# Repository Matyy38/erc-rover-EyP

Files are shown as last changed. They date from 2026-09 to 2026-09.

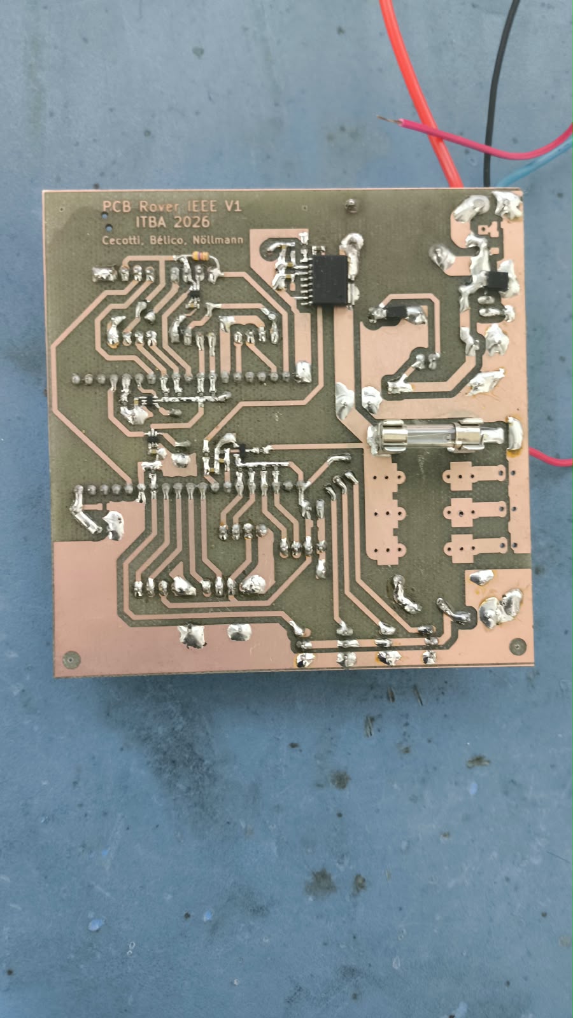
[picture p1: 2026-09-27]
audiovisual-presentacion/Foto pcb2.jpeg

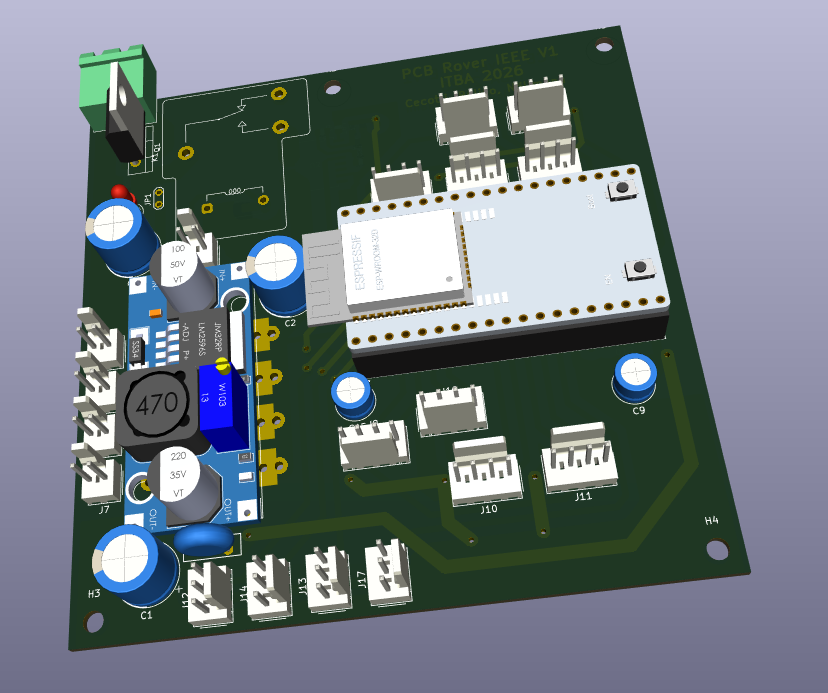
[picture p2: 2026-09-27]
audiovisual-presentacion/PCB Simulación 3D.png

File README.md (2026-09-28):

---
titulo: Rover ERC — subsistema de Electrónica y Potencia
estado: vigente
fecha: 2026-09-28
fuente: migracion.md (árbol y mapeo de los cuatro documentos fuente)
---

# Rover ERC — Electrónica y Potencia

Documentación del subsistema de Electrónica y Potencia del rover del European Rover Challenge
(IEEE ITBA I+D). Dos frentes: el **rover final** (40 kg, bus de 24 V, swerve de 4 ruedas) y el **modelo a
escala**, que es un instrumento de medición para cerrar la especificación de motores sin comprar
motores de tamaño real a ciegas.

**Empezá por [00-contexto/00-contexto-maestro.md](00-contexto/00-contexto-maestro.md).** Tiene el
estado, los conflictos abiertos y el mapa.

---

## Árbol

```
rover-erc/
├── README.md
├── CLAUDE.md
├── 00-contexto/
│   ├── 00-contexto-maestro.md
│   ├── 01-alcance-y-fronteras.md
│   ├── 02-filosofia-de-diseno.md
│   ├── 03-conflictos-abiertos.md
│   ├── 04-decisiones-descartadas.md
│   └── 05-principios-transversales.md
├── 10-rover-final/
│   ├── 10-locomocion/
│   │   ├── requisitos-motor.md
│   │   └── candidatos-motores.md
│   └── 20-potencia/
│       ├── presupuesto-corriente.md
│       └── cableado-y-protecciones.md
├── 20-modelo-escala/
│   ├── 00-estado-actual.md
│   ├── 10-metodologia-similitud.md
│   ├── 20-electronica/
│   │   ├── arquitectura-electrica.md
│   │   ├── encoders-pcnt.md
│   │   ├── drivers-bts7960.md
│   │   ├── direccion-swerve-servos.md
│   │   ├── sensado-corriente.md
│   │   └── protecciones-desacople.md
│   ├── 30-pcb/
│   │   ├── especificacion.md
│   │   ├── decisiones-layout.md
│   │   ├── mapa-conectores.md
│   │   ├── bom.md
│   │   └── pendientes-de-verificacion.md
│   ├── 40-firmware/
│   │   └── mapa-gpio.md
│   └── 50-ensayos/
│       ├── instrumentacion.md
│       └── plan-de-ensayos.md
├── 30-componentes/
├── 40-proveedores-costos/
├── 90-archivo/
│   ├── analisis-sensado-superado.md
│   ├── migracion-2026-09-16.md
│   └── fuentes-originales/
├── audiovisual-presentacion/
└── pcb_V1/
```

---

## Índice

### 00-contexto

| Archivo | Qué tiene |
|---|---|
| [00-contexto-maestro.md](00-contexto/00-contexto-maestro.md) | Documento raíz: estado de los dos frentes, conflictos abiertos, instrumentación, próximos pasos y mapa del repo. |
| [01-alcance-y-fronteras.md](00-contexto/01-alcance-y-fronteras.md) | Qué entra y qué no en el subsistema, con la tabla de interfaces con Mecánica. |
| [02-filosofia-de-diseno.md](00-contexto/02-filosofia-de-diseno.md) | Las reglas no negociables y dónde se aplica cada una. |
| [03-conflictos-abiertos.md](00-contexto/03-conflictos-abiertos.md) | Los tres conflictos que bloquean decisiones y la consulta consolidada a Mecánica. |
| [04-decisiones-descartadas.md](00-contexto/04-decisiones-descartadas.md) | Tabla única de lo que se evaluó y no quedó, con el motivo. |
| [05-principios-transversales.md](00-contexto/05-principios-transversales.md) | Las trece reglas ganadas en el proyecto que aplican más allá de su caso. |

### 10-rover-final

| Archivo | Qué tiene |
|---|---|
| [10-locomocion/requisitos-motor.md](10-rover-final/10-locomocion/requisitos-motor.md) | Torque, velocidad y potencia por rueda; discrepancias de diámetro; implicancias eléctricas. |
| [10-locomocion/candidatos-motores.md](10-rover-final/10-locomocion/candidatos-motores.md) | Estado por candidato, criterio de reducción y criterio de búsqueda del reemplazo. |
| [20-potencia/presupuesto-corriente.md](10-rover-final/20-potencia/presupuesto-corriente.md) | Del torque medido a la corriente de la PDB: escenarios, techo de tracción, potencia continua. |
| [20-potencia/cableado-y-protecciones.md](10-rover-final/20-potencia/cableado-y-protecciones.md) | Calibres, fusibles y la cadena conector-fusible-cable del rover final. |

### 20-modelo-escala

| Archivo | Qué tiene |
|---|---|
| [00-estado-actual.md](20-modelo-escala/00-estado-actual.md) | Estado de validación de la placa por bloque y cambios confirmados respecto del PDF. |
| [10-metodologia-similitud.md](20-modelo-escala/10-metodologia-similitud.md) | λ vigente, revisión de escala por la masa real, altura del CM y constantes recalculadas. |
| [20-electronica/arquitectura-electrica.md](20-modelo-escala/20-electronica/arquitectura-electrica.md) | Cadena de potencia, rieles y presupuesto del riel de 3,3 V. |
| [20-electronica/encoders-pcnt.md](20-modelo-escala/20-electronica/encoders-pcnt.md) | Acondicionamiento de los ocho canales y uso del periférico PCNT. |
| [20-electronica/drivers-bts7960.md](20-modelo-escala/20-electronica/drivers-bts7960.md) | Habilitaciones, estado del canal 4 en el arranque (V1) y desacople local. |
| [20-electronica/direccion-swerve-servos.md](20-modelo-escala/20-electronica/direccion-swerve-servos.md) | Margen del riel de servos (V3), el PTC único y el estado en el arranque. |
| [20-electronica/sensado-corriente.md](20-modelo-escala/20-electronica/sensado-corriente.md) | TMCS1126B4: qué mide, rango, acondicionamiento, umbral de OC (V9) y calibración. |
| [20-electronica/protecciones-desacople.md](20-modelo-escala/20-electronica/protecciones-desacople.md) | Capas de protección, polaridad inversa (V2), TVS (V5, V6), inrush del relé (V7). |
| [30-pcb/especificacion.md](20-modelo-escala/30-pcb/especificacion.md) | Datos generales, corrientes de diseño y anchos de pista. |
| [30-pcb/decisiones-layout.md](20-modelo-escala/30-pcb/decisiones-layout.md) | Masas en estrella, ruteo del TMCS1126, potencia, analógico y mecánica. |
| [30-pcb/mapa-conectores.md](20-modelo-escala/30-pcb/mapa-conectores.md) | Tabla completa de J1 a J19, márgenes de los conectores (V4) y convenciones de cableado. |
| [30-pcb/bom.md](20-modelo-escala/30-pcb/bom.md) | Lista por referencia, ítems sin valor definido y compras fuera de placa. |
| [30-pcb/pendientes-de-verificacion.md](20-modelo-escala/30-pcb/pendientes-de-verificacion.md) | Los doce puntos V1 a V12, cómo se confirma cada uno y dónde se discute. |
| [40-firmware/mapa-gpio.md](20-modelo-escala/40-firmware/mapa-gpio.md) | **Fuente única de verdad del pinout**, con la estrategia de arranque seguro. |
| [50-ensayos/instrumentacion.md](20-modelo-escala/50-ensayos/instrumentacion.md) | Cadena de medición, tiro en barra, instrumento externo y riesgos de medición. |
| [50-ensayos/plan-de-ensayos.md](20-modelo-escala/50-ensayos/plan-de-ensayos.md) | Ensayo de ángulo de deslizamiento, Ensayo A fuera de la PDB y próximos pasos. |

### Carpetas por llenar y archivo

| Archivo | Qué tiene |
|---|---|
| [30-componentes/README.md](30-componentes/README.md) | Ficha por componente y enlaces a hojas de datos. Vacía. |
| [40-proveedores-costos/README.md](40-proveedores-costos/README.md) | Proveedores y costos de importación. Vacía. |
| [90-archivo/README.md](90-archivo/README.md) | Versiones superadas y ramas muertas. **No usar como fuente.** |
| [90-archivo/analisis-sensado-superado.md](90-archivo/analisis-sensado-superado.md) | El análisis que suponía que el TMCS1126 medía el total de la PDB, con su nota de trazabilidad. |
| [90-archivo/migracion-2026-09-16.md](90-archivo/migracion-2026-09-16.md) | Plan con el que se armó este árbol a partir de los cuatro documentos fuente. |
| [90-archivo/fuentes-originales/README.md](90-archivo/fuentes-originales/README.md) | Los cuatro documentos previos a la migración, sin tocar. |

### Material para el equipo

| Archivo | Qué tiene |
|---|---|
| [audiovisual-presentacion/guia-ingreso-EyP-2026-09.docx](audiovisual-presentacion/guia-ingreso-EyP-2026-09.docx) | Guía de ingreso: resumen del repo para ponerse al día. Corte al 28-sep-2026; si no coincide con el repo, manda el repo. |
| [audiovisual-presentacion/presentacion-ingreso-EyP-2026-09.pptx](audiovisual-presentacion/presentacion-ingreso-EyP-2026-09.pptx) | Presentación de ingreso al subsistema. |
| [pcb_V1/](pcb_V1/) | Proyecto de KiCad de la placa del modelo, para descargar. El análisis está en `20-modelo-escala/`. |

---

## Reglas de trabajo sobre el repo

- **El mapa de GPIO es fuente única de verdad.** Si una tabla de pines aparece en otro archivo, ese
  archivo enlaza al mapa, no lo copia.
- **Los puntos V1 a V12 son hipótesis, no defectos.** Al cerrar uno, se actualiza su fila con el
  resultado de la medición.
- **La placa ya está fabricada y soldada.** Toda propuesta de cambio dice si es un corte y un puente,
  un componente a reemplazar, o un rediseño.
- **Los archivos de KiCad están en `pcb_V1/` para descargar.** Lo que salió de analizarlos está
  asentado en markdown: los datos se buscan ahí.
- **Cada dato técnico tiene un solo dueño.** El contexto maestro es un índice de estado: resume y
  enlaza, no copia números. Si hay diferencia, manda el archivo de detalle.
- **`90-archivo/` es historia.** No se usa como fuente.

## Convenciones

- Contenido en español. Nombres de archivo en minúscula, sin tildes ni espacios, con guiones.
- Carpetas numeradas para forzar orden de lectura.
- Frontmatter YAML con `titulo`, `estado`, `fecha` y `fuente` en cada archivo.
- Enlaces markdown relativos, nunca wikilinks.
- Entre 40 y 400 líneas por archivo de contenido. Por debajo de 40, fusionar con el contiguo.
- **Los archivos de KiCad se versionan en `pcb_V1/` solo para descarga.** Lo que sale de
  analizarlos se documenta en markdown.
- Registro de decisiones = tabla de descartados, no ADR formales.
- Dentro de tablas, decimales en texto plano con coma. LaTeX solo fuera de tablas.

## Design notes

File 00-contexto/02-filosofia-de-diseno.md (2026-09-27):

---
titulo: Filosofía de diseño — reglas no negociables
estado: vigente
fecha: 2026-09-16
fuente: 00-contexto-maestro.md §3
---

# Filosofía de diseño

Las reglas que no se discuten en cada decisión porque ya se discutieron una vez. Versión corta en el
[contexto maestro](00-contexto-maestro.md) §2.

---

## 1. Reglas

- **COTS primero.** PCB custom solo si lo justifica espacio, peso o ruteo de EMI.
- **Sobredimensionar por seguridad, optimizar por peso y espacio.**
- **Star grounding estricto.** El retorno de motores no comparte cobre con el de lógica ni con el
  analógico en ningún tramo.
- **Cable de silicona en potencia.** Norma AWG.
- **Prohibido protoboard y cables Dupont.** Fretting bajo vibración, contactos intermitentes
  imposibles de diagnosticar. Siempre conectores con traba: XT60, Molex, Anderson, bornera.
- **E-Stop y fusibles innegociables.** El fusible protege el cableado, no la carga.
- **Punteras tubulares** en todo cable multifilar que entre a bornera.

Escenarios contra los que se juzga todo diseño: vibración continua, corriente de bloqueo, estrés
térmico.

---

## 2. Dónde se aplica cada regla

Ninguna de estas reglas es abstracta: todas tienen su caso concreto en la placa del modelo o en el
cableado del rover final. La tabla es el índice de esos casos.

| Regla | Caso concreto | Dónde se discute |
|---|---|---|
| COTS primero | Módulos BTS7960, LM2596 y ESP32-DEVKITC comprados hechos; la PCB propia es solo la distribución | [bom.md](../20-modelo-escala/30-pcb/bom.md) |
| Sobredimensionar por seguridad | Anchos de pista IPC-2221 con ΔT de 10 °C, planos en ambas caras reforzados con estaño | [especificacion.md](../20-modelo-escala/30-pcb/especificacion.md) |
| Star grounding estricto | Dos vertidos de masa unidos en un solo punto; el retorno del sensor va a masa lógica | [decisiones-layout.md](../20-modelo-escala/30-pcb/decisiones-layout.md) |
| Cable de silicona, norma AWG | Tabla de calibres por tramo, de 12–14 AWG en batería a 22–24 AWG en señal | [mapa-conectores.md](../20-modelo-escala/30-pcb/mapa-conectores.md) |
| Prohibido protoboard y Dupont | Conectores Molex KK-254 con traba en toda la placa; XT en el instrumento externo | [mapa-conectores.md](../20-modelo-escala/30-pcb/mapa-conectores.md) |
| E-Stop y fusibles | Seta NC sobre la bobina del relé, fusible por driver, PTC en el riel de servos | [protecciones-desacople.md](../20-modelo-escala/20-electronica/protecciones-desacople.md) |
| El fusible protege el cableado | La cadena conector-fusible-cable del rover final se dimensiona junta | [cableado-y-protecciones.md](../10-rover-final/20-potencia/cableado-y-protecciones.md) |
| Punteras tubulares | Obligatorias en todo multifilar que entre a bornera a tornillo | [decisiones-layout.md](../20-modelo-escala/30-pcb/decisiones-layout.md) |

---

## 3. Los tres escenarios de juicio

- **Vibración continua.** Es la que descarta el protoboard y el Dupont, la que obliga a sujetar los
  mazos pesados al chasis cerca de la placa, y la que hace que todo conector tenga traba.
- **Corriente de bloqueo.** Es el peor caso eléctrico: 22 A con las cuatro ruedas trabadas en el
  modelo. Define fusibles, conectores, anchos de pista y el límite del driver. No es condición de
  operación, es condición de falla, pero el hardware la tiene que sobrevivir.
- **Estrés térmico.** Es el que aparece tarde y sin aviso: la disipación de Q1 (V2), la temperatura
  del AMS1117 con el LM2596 en 7,2 V (V10), el margen térmico del motor en continuo.

Las reglas ganadas de estos escenarios que trascienden su caso original están en
[05-principios-transversales.md](05-principios-transversales.md).

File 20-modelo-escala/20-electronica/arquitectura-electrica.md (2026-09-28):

---
titulo: Arquitectura eléctrica de la PCB del modelo
estado: vigente
fecha: 2026-09-27
fuente: pcb-modelo-escala.md, sección arquitectura-electrica
---

# Arquitectura eléctrica

Cadena de potencia, rieles y presupuesto del 3,3 V de la placa del modelo a escala. El mapeo de pines
del ESP32 y la estrategia de arranque seguro **no están acá**: viven en
[40-firmware/mapa-gpio.md](../40-firmware/mapa-gpio.md), que es la fuente única de verdad del pinout.

### Cadena de potencia

```
                         NODO A (12 V protegido, permanente)
 J1          Q1                 |
[Bat +]--->[D  S]-------+-------+--- D1 (TVS SM6T15A) --- GND
 12V/7Ah    IRF9540N    |       |
                        |       +--- D5+R16 (LED de presencia)
                   R14 10k      |
                   D4 16V       +--- JP1 ---+--- C7 1000u
                    (gate)      |           |
                                |           +--- U2 LM2596  --> RIEL "+5V" (a setear en 7,2 V)
                                |           |                     |
                                |           +--- J2 (SETA NC)     +--- ESP1.19 (VIN del devkit)
                                |                  |              +--- C9 100u + C10 1u
                                |                  v              +--- F2 (PTC) --> C1 1000u --> J12/J13/J14/J17 (4 servos)
                                |            K1 bobina A2
                                |            D3 en antiparalelo
                                |            K1 bobina A1 --> GND
                                |
                                +--- K1 contacto 11 (comun)
                                          |
                                     (NO) 14
                                          |
                                     U3 IN- [TMCS1126B4] IN+
                                                          |
                                                    RIEL +12V CONMUTADO
                                                          |
                                          +------+--------+--------+------+
                                          F5     F3       F4       F6     C2 1000u + R6 (divisor)
                                          |      |        |        |
                                         J6     J4       J5       J7
                                      driver1 driver2  driver3  driver4
```

> **Cambios del 27-sep-2026 sobre este diagrama:**
> - **Q1 está puenteado.** El nodo A queda unido directo a la batería; la polaridad se protege con un
>   conector que solo entra en un sentido. Ver [protecciones-desacople.md](protecciones-desacople.md).
> - **ACS712 en la pata de motor de una rueda delantera**, entre driver y motor, fuera de la placa.
>   Se alimenta con un regulador lineal de 5 V propio desde el riel "+5V" y se lee con un ADS1115 en
>   el bus I2C. Ver [sensado-corriente.md](sensado-corriente.md).
> - La batería de plomo alimenta el bus de tracción **sin regular** (10,5 a 14,4 V). Los ensayos lo
>   compensan con lazo cerrado de velocidad y registro de tensión y ciclo de trabajo, no con un
>   convertidor. Ver [50-ensayos/plan-de-ensayos.md](../50-ensayos/plan-de-ensayos.md).

### Rieles

| Riel | Origen | Tensión real | Cargas | Protección propia |
|---|---|---|---|---|
| Batería | J1 | 10,5 - 14,4 V (plomo-ácido 12 V / 7 Ah) | todo | Fusible aéreo (off-board) |
| Nodo A | salida de Q1 (**Q1 puenteado**: nodo A = batería) | Vbat | LM2596, bobina del relé, LED | D1 (TVS); polaridad por conector de un solo sentido |
| +12V conmutado | contacto NO de K1, vía U3 | Vbat - caída del relé - 0,7 mΩ del sensor | 4 drivers, C2, divisor de batería | F3..F6 (uno por driver) |
| "+5V" (nombre de red) | U2 LM2596 | **a setear en 7,2 V**, no 5 V | ESP32 VIN + 4 servos | ninguna en la entrada del ESP32 |
| Riel de servos | +5V detrás de F2 | 7,2 V menos la caída del PTC | 4 servos | F2 (PTC rearmable) |
| +3,3 V | AMS1117 del devkit ESP32 | 3,3 V | ESP32, TMCS, MPU, encoders, pull-ups, enables de los BTS, 3 NLAS | ninguna |

Dos consecuencias arquitectónicas que conviene tener presentes:

1. **La seta corta solamente la tracción.** El LM2596 y la bobina cuelgan del nodo A, aguas arriba
   del relé. Al apretar la seta se desenergiza la bobina, se abren los contactos y muere el bus de
   los drivers, pero **los servos de dirección y el ESP32 siguen alimentados**. Para el modelo a
   escala eso es deseable (la telemetría sobrevive al corte). Si en algún ensayo se necesita que los
   servos también caigan, hay que pasar el LM2596 aguas abajo del relé, y ahí se pierde la
   telemetría post-corte.
2. **V_bat se mide después del relé.** El divisor R6/R5 cuelga del riel +12 V conmutado. Con la seta
   apretada el ESP32 lee 0 V, y el corte por software a 10,5 V se dispararía como falso positivo.
   Se contempla en firmware (enmascarar el corte por baja tensión si la tensión cae de golpe a cero
   con corriente nula) o se mueve el divisor al nodo A.

### Presupuesto del riel de 3,3 V

Todo el 3,3 V de la placa sale del AMS1117 que trae el módulo ESP32. No hay regulador de 3,3 V
propio en la PDB.

| Carga | Consumo estimado |
|---|---|
| ESP32 con Wi-Fi activo | 80 - 120 mA promedio, picos de 300 mA |
| U3 TMCS1126 (Iq) | 11 - 14,5 mA |
| MPU6050 | ~4 mA |
| ADS1115 (27-sep) | <1 mA |
| 4 encoders Hall | 40 - 80 mA (**medir**, es la incógnita grande) |
| 8 pull-ups de 4,7 k, peor caso todos en bajo | 5,6 mA |
| VCC lógico de los 4 BTS7960 + enables | 10 - 30 mA (**medir**) |
| 3 NLAS4157 | despreciable |
| **Total estimado** | **150 - 250 mA, picos de 400 mA** |

Con el LM2596 en 5 V: el AMS1117 disipa (5 - 3,3) x 0,25 = 0,43 W. Se banca.

Con el LM2596 en 7,2 V (la idea anotada en el esquemático para los servos): disipa
(7,2 - 3,3) x 0,25 = 0,98 W. En SOT-223 sobre el cobre mínimo de un devkit, con resistencia térmica
del orden de 60 a 110 °C/W, son 60 a 110 °C de salto sobre ambiente. Vale la pena medir la
temperatura del regulador antes de dejar el sistema andando mucho rato a 7,2 V (V10).

Si el número da alto, tres salidas:
- (a) Dos convertidores: uno a 5 V para el ESP32 y otro a 7,2 V solo para los servos.
- (b) Un regulador de 3,3 V propio en la PDB desde el nodo A, alimentando el ESP32 por 3V3 directo.
  Ojo con no alimentar simultáneamente 5V y 3V3.
- (c) Dejar el LM2596 en 5 V y aceptar menos torque en los servos.

### Mapeo de pines del ESP32 y arranque seguro

Movidos a [40-firmware/mapa-gpio.md](../40-firmware/mapa-gpio.md). Ahí están la tabla completa de
GPIO extraída del `.sch`, la advertencia de numeración de pines del símbolo de KiCad, y la estrategia
de arranque seguro con los conmutadores NLAS4157. **No copiar esa tabla acá ni en ningún otro
archivo:** duplicar el pinout es la forma más probable de romper algo.

De ahí salen dos datos que se usan en este archivo: no queda ningún GPIO libre, y los puntos V1 y
V10 tocan directamente esta arquitectura.

### Notas de arquitectura

- El número de driver (1..4) **no está asociado a una rueda** en ningún lado del esquemático. Los
  encoders sí (FR, FL, RL, RR) y los servos están numerados 1..4. Conviene fijar la correspondencia
  driver N <-> rueda <-> servo N y rotularla en el mazo y en el firmware.
- No hay watchdog externo ni forma de resetear la etapa de potencia sin la seta.
- No hay CAN en esta etapa (decisión explícita del PDF, sigue vigente).

---

## Relacionado

- Protecciones del nodo A, TVS, relé y polaridad inversa: [protecciones-desacople.md](protecciones-desacople.md)
- Sensor de corriente en la rama conmutada: [sensado-corriente.md](sensado-corriente.md)
- Riel de servos y margen del LM2596 (V3): [direccion-swerve-servos.md](direccion-swerve-servos.md)
- Puntos V10 (temperatura del AMS1117) y V12 (lectura de V_bat con la seta apretada): [30-pcb/pendientes-de-verificacion.md](../30-pcb/pendientes-de-verificacion.md)

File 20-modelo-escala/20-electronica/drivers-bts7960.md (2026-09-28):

---
titulo: Drivers BTS7960 del modelo a escala
estado: vigente
fecha: 2026-09-27
fuente: pcb-modelo-escala.md, sección drivers-bts7960
---

# Drivers BTS7960

Validado: se probó un puente H de cada unidad y funcionaron.

### Interfaz

Cada driver usa **dos conectores separados**: uno de señal (4 vías) y uno de potencia (2 vías).

- **Señal:** J10 (BTS7960_1), J11 (BTS7960_2), J15 (BTS7960_3) y J19 (BTS7960_4), Molex KK-254 de 4
  vías. Llevan L_PWM, R_PWM, +3,3 V y GND. En J19, **R_PWM_4 no viene directo del ESP32 sino de U1**.
- **Potencia:** J6 (driver 1), J4 (driver 2), J5 (driver 3) y J7 (driver 4), Molex KK-254 de 2 vías,
  cada uno detrás de su fusible.

Pinout completo con huella y corriente nominal en
[30-pcb/mapa-conectores.md](../30-pcb/mapa-conectores.md). GPIO de origen de cada línea PWM en
[40-firmware/mapa-gpio.md](../40-firmware/mapa-gpio.md).

La correspondencia fusible-driver **no es correlativa** (F3 va al driver 2, F5 al driver 1).
Conviene dejarlo serigrafiado.

### Habilitaciones

Los `R_EN` y `L_EN` de los cuatro módulos se alimentan desde el pin 3 de cada conector de señal, que
va a +3,3 V permanente. Es decir: **los puentes H están habilitados desde que hay 3,3 V, y el estado
de reposo se delega enteramente a las líneas PWM**. Esto ahorra 4 GPIO, con dos consecuencias:

1. No hay forma de apagar los puentes por hardware sin cortar el bus de 12 V con el relé.
2. Queda libre el único mecanismo de apagado rápido disponible. Ver la propuesta en
   [sensado-corriente.md](sensado-corriente.md) para engancharle el pin OC del TMCS1126.

### Estado del canal 4 durante el arranque (V1)

De la tabla de verdad del NLAS4157 se desprende que, durante la ventana de arranque del ESP32,
`R_PWM_4` quedaría en 3,3 V:

- IO5 arranca en ALTO (pull-up interno, latcheado por el strapping).
- U1 tiene B1 a +3,3 V y B0 a GND, así que su salida A copia a S.
- L_PWM_4 (IO23) es un GPIO común: al reset queda como entrada sin pull. El BTS7960 tiene pull-down
  interno en IN, lo cual cubre a L_PWM_4 pero no a R_PWM_4.
- Los enables están activos de forma permanente.

Si el análisis es correcto, el driver 4 recibiría R_PWM alto y L_PWM bajo, y el motor giraría hasta
que el firmware tome el control. **Esto hay que confirmarlo o descartarlo con osciloscopio**, porque
hay al menos dos cosas que podrían hacer que no pase: el mapeo de números de pin del símbolo
reutilizado (U1 usa el símbolo `RF_Switch:MASWSS0136` renombrado a NLAS4157; si la numeración del
símbolo o de la huella no coincidiera con el NLAS4157 real, la conclusión cambia), y el
comportamiento real de la entrada del módulo BTS7960 a 3,3 V de VCC.

Medición concreta: disparar el osciloscopio en el flanco de EN del ESP32 y mirar R_PWM_4 y L_PWM_4
durante todo el arranque, con el conector de potencia del driver 4 desconectado.

> **Mitigación aplicada (27-sep-2026).** Se soldó una **resistencia de pull-up en L_PWM_4** (valor
> a asentar). Durante el arranque las dos entradas del driver 4 quedan en alto: las dos llaves
> superiores encendidas, los dos bornes del motor al mismo potencial, motor frenado y sin corriente.
> Es un agregado de componente, sin cortes. **V1 sigue abierto hasta verificarlo:** osciloscopio en
> R_PWM_4 y L_PWM_4 durante el arranque, confirmando que L_PWM_4 supera el umbral alto frente al
> pull-down interno del driver, y después, con el motor conectado, que no se mueve al encender.
> Una consecuencia a tener en cuenta en firmware: si el ESP32 se cuelga con IO23 en alta impedancia,
> L_PWM_4 queda en alto.

La alternativa que se había propuesto era **invertir B0/B1 en U1** (B1 a GND, B0 a +3,3 V) e
invertir esa salida PWM por hardware en la matriz de GPIO del LEDC, que no cuesta nada. Si la placa
ya está fabricada son dos cortes y dos puentes. Conviene aplicar el mismo criterio a U4 y U5 aunque
ahí no sea crítico, para que los tres canales queden con la misma convención.

### Otros puntos de los drivers

- **VCC lógico a 3,3 V.** Los módulos BTS7960 comerciales están especificados con VCC de 5 V. Con
  3,3 V andan (el IN es un Schmitt trigger compatible TTL/CMOS) y ya se comprobó en banco, pero se
  está fuera de la especificación nominal del módulo. Conviene verificar la conmutación en todo el
  rango de ciclo de trabajo, no solo en un punto.
- **Los pines IS quedan sin usar.** Consecuencia: no hay medición de corriente por rueda desde la
  placa, solo la total (más la rueda del ACS712, ver
  [sensado-corriente.md](sensado-corriente.md)). **En revisión desde el 27-sep:** con el ADS1115
  sobra un canal. Propuesta: no usarlo como canal de medición en esta campaña (la relación de IS
  tiene mucha dispersión, a menos de ~1 A la domina el error de cero, y con PWM también necesita la
  corrección por D), y a lo sumo cablear un canal experimental en la rueda del ACS712 para medir su
  relación real. Si en falla IS entrega varios mA, sobre 1 k supera los 3,3 V del ADS: resistencia de
  carga ≤ 680 Ω y 10 k en serie. Valores a confirmar en la hoja de datos. Si la relación resulta
  estable, un segundo ADS1115 (0x49) daría las cuatro ruedas.
- **No hay pull-down en las 8 líneas PWM.** Dependen del pull-down interno del BTS7960 durante el
  boot. Mejora barata: un pull-down de 10 k **del lado del driver** (soldado en el módulo o en el
  conector). Del lado del GPIO no protege contra un cable desconectado.
- **Terminación serie.** Con 60 a 100 cm de cable y flancos rápidos, 220 Ω en serie en el origen de
  cada línea PWM ayuda. No están en la placa; se pueden agregar en el conector.
- **Desacople local.** El PDB tiene C2 de 1000 uF, pero los drivers están a 60-100 cm. La
  inductancia de ese cable (del orden de 1 uH/m) domina a frecuencias de conmutación. **Cada
  BTS7960 necesita su propio desacople físicamente en el módulo**: 2 x 470 uF / 25 V / 105 °C de
  bajo ESR más 100 nF cerámico en los bornes. Es hardware fuera de la PCB pero es parte del diseño.

---

El punto V1 y su medición están resumidos en [30-pcb/pendientes-de-verificacion.md](../30-pcb/pendientes-de-verificacion.md).

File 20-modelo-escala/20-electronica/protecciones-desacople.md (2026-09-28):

---
titulo: Protecciones y desacople de la PCB del modelo
estado: vigente
fecha: 2026-09-27
fuente: pcb-modelo-escala.md, sección protecciones-desacople
---

# Protecciones y desacople

> **Cambio (27-sep-2026): Q1 quedó puenteado y no se usa.** La protección contra polaridad inversa
> pasa a ser un conector que solo entra en un sentido: es la alternativa que el propio PDF mencionaba
> (ver más abajo). V2 deja de aplicar. Lo que se pierde es la protección contra el error de conectar
> con cables sueltos o pinzas: **nunca alimentar la placa si no es por ese conector**. La protección
> contra cortocircuito sigue siendo el fusible general. El análisis de Q1 queda abajo como registro.

### Capas de protección

| Capa | Componente | Qué protege |
|---|---|---|
| Fusible general | aéreo, off-board | cableado de batería |
| Polaridad inversa | ~~Q1 IRF9540N + R14 10 k + D4 zener 16 V~~ **Q1 puenteado.** Conector de un solo sentido | toda la placa |
| Sobretensión | D1 SM6T15A en el nodo A | toda la placa |
| Corte de emergencia | J2 (seta NC) -> bobina K1 -> contacto NO | rama de tracción |
| Antirretorno de bobina | D3 en antiparalelo con la bobina | contactos de la seta |
| Sobrecorriente por rama | F3..F6, uno por driver | cableado a cada driver |
| Sobrecorriente en servos | F2 (PTC) | rama de servos |
| Sobrecorriente electrónica | pin OC del TMCS1126 | hoy sin usar (ver V9) |
| Protección de ADC | D2 BAT54S en V_bat | entrada IO32 |
| Indicación | D5 + R16 2,2 k (~4,5 mA) | — |

### Circuito de polaridad inversa

El circuito de compuerta está bien resuelto: el drenador va a la batería y la fuente a la carga, de
manera que el diodo intrínseco conduce en el sentido normal de operación y bloquea con la batería
invertida. La compuerta se lleva a masa por R14 (10 k) y el zener D4 de 16 V limita V_GS, que en el
IRF9540N tiene un máximo de ±20 V. Correcto.

**Disipación en Q1 (V2).** El IRF9540N es canal P, -100 V, -23 A, con **R_DS(on) = 117 mΩ** típico a
VGS = -10 V, en TO-220 vertical. La aritmética de disipación:

| Corriente de bus | Disipación en Q1 | Salto térmico sin disipador (~62 °C/W) |
|---|---|---|
| 1 A | 0,12 W | 7 °C |
| 3 A | 1,05 W | 65 °C |
| 5 A | 2,9 W | 181 °C |
| 10 A | 11,7 W | fuera de rango |
| 22 A (bloqueo) | 56,6 W | fuera de rango |

En banco con poca carga no se nota; el problema aparecería con las cuatro ruedas cargadas. **La
medición que lo define es tocar/medir la temperatura de Q1 con el rover andando sobre terreno**, y
medir la caída de tensión entre drenador y fuente con corriente conocida (a 5 A deberían ser unos
0,6 V si el R_DS(on) es el del datasheet).

Si el número da alto, reemplazos que mantienen el mismo circuito de compuerta:

| Candidato | V_DS | I_D | R_DS(on) | Encapsulado | Disipación a 22 A |
|---|---|---|---|---|---|
| **IRF4905** | -55 V | -74 A | 20 mΩ | TO-220 | 9,7 W (con disipador) |
| AOD4185 / AOB4185 | -40 V | -40 A | ~10 mΩ | TO-252 / TO-263 | 4,8 W |

Alternativa que el propio PDF menciona: eliminar el circuito de polaridad inversa y confiar en un
conector polarizado (XT60). Pierde protección contra el error humano de conectar con caimanes, pero
elimina una fuente de calor y de caída.

### TVS: tensión de trabajo y ubicación (V5, V6)

**V5.** D1 es un **SM6T15A**: 600 W, tensión de trabajo (standoff) de aproximadamente 12,8 V,
ruptura mínima de 14,3 V. Una batería de plomo-ácido flota entre 13,5 y 13,8 V y en carga cíclica
llega a 14,4 V. Con el cargador conectado y el rover energizado, el TVS podría quedar cerca de su
ruptura y conducir. Medición: con la batería recién cargada, medir la corriente de fuga por D1 (o
simplemente su temperatura) con el rover encendido.

Si conduce, reemplazo: **SM6T18A** (standoff 15,3 V) o **SMBJ16A / SMCJ16A** (standoff 16 V). La
tensión de recorte resultante, del orden de 26 V, es segura: los BTS7960 admiten hasta 45 V.

**V6.** El TVS está en el nodo A, aguas arriba del relé. Cuando la seta abre los contactos con los
motores girando, la energía inductiva queda del lado de los drivers, donde no hay TVS: solo C2
(1000 uF), que absorbe la mayor parte, y los diodos intrínsecos de los puentes. Conviene ver con
osciloscopio qué pico aparece en el riel conmutado al abrir la seta a plena marcha. Si es alto, un
segundo TVS (SMBJ16A alcanza) entre el riel conmutado y GND, cerca de C2.

La ubicación del TVS que sí está es correcta en un aspecto: queda **después** del MOSFET de
polaridad inversa, que es donde tiene que ir.

### Inrush del contacto del relé (V7)

K1 es un relé automotriz de 12 V / 40 A. Al cerrar conecta el nodo A contra C2 (1000 uF) más el
desacople local de los drivers (4 x 940 uF si se monta lo recomendado), del orden de **4,8 mF**. La
energía que va al arco de cierre es del orden de `½CV² = 350 mJ` por encendido.

Un contacto de 40 A lo tolera, pero repetido erosiona y puede terminar soldando los contactos. El
síntoma es que la seta deja de cortar y nadie se entera hasta que hace falta. **Verificación
periódica: con la seta apretada, medir continuidad entre el nodo A y el riel conmutado.** Debe ser
circuito abierto.

Mitigación estándar si aparece: **resistencia de precarga de 22 Ω / 5 W en paralelo con el
contacto**. La constante de carga pasa a `22 × 4,8 mF = 106 ms`, o sea que los capacitores ya están
cargados cuando el contacto cierra. No requiere lógica. Para el arco de apertura, un snubber RC
(100 Ω + 100 nF en serie, en paralelo con el contacto).

### Desacople actual

| Riel / punto | Capacitores | Comentario |
|---|---|---|
| Nodo A (entrada del LM2596) | C7 1000 uF | correcto |
| +12 V conmutado | C2 1000 uF | correcto en la placa; el desacople remoto de los drivers es aparte |
| Salida del LM2596 ("+5V") | C9 100 uF + C10 1 uF | correcto |
| Riel de servos (detrás de F2) | C1 1000 uF | correcto en topología |
| +3,3 V | C15 100 uF + C11 1 uF | conviene sumar un 100 nF cerámico pegado al pin 3V3 |
| VS del TMCS1126 | C4 100 n + FB1 + C3 100 n | filtro en pi, muy bien |
| VOC del TMCS1126 | C5 1 uF | el fabricante sugiere 10 uF |
| VCC de cada NLAS4157 | C12, C13, C14 (100 n) | uno por chip, correcto |
| V_bat (ADC) | C6 100 n | con la impedancia de Thevenin del divisor (1,8 k) da un polo en 883 Hz |
| Vout_CS (ADC) | C8 100 n | con R15 de 1 k da un polo en 1,59 kHz |

El único agregado que falta es un 100 nF en 3V3: los electrolíticos de 100 uF tienen ESR e
inductancia que los vuelve poco efectivos por encima de unos cientos de kHz, que es el rango donde
el ESP32 mete escalones de corriente al transmitir por Wi-Fi.

---

Los puntos V2, V5, V6 y V7 y sus mediciones están resumidos en [30-pcb/pendientes-de-verificacion.md](../30-pcb/pendientes-de-verificacion.md).

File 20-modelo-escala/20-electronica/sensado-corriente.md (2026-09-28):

---
titulo: Sensado de corriente — TMCS1126B4 y ACS712 de respaldo
estado: vigente
fecha: 2026-09-27
fuente: pcb-modelo-escala.md, sección sensado-corriente; decisiones del 27-sep-2026 (ADS1115 y ACS712)
---

# Sensado de corriente

### Qué se eligió y por qué

El ACS712-30A del PDF quedó cancelado **como sensor de placa**. En su lugar hay **un TMCS1126B4**
(Texas Instruments), sensor Hall con aislación reforzada, en encapsulado SOIC-10 ancho.

> **27-sep-2026:** el ACS712-30A vuelve, con otro rol: segundo sensor a bordo, en la pata de motor de
> una rueda, leído por el ADS1115. Ver [ACS712 de respaldo](#acs712-de-respaldo-27-sep-2026) al final
> de este archivo.

| Parámetro | Valor |
|---|---|
| Sensibilidad | **100 mV/A** |
| Tensión de salida a corriente cero (VREF interno) | **1,65 V** (variante B, bidireccional) |
| Rango lineal con VS = 3,3 V | **±15,5 A** |
| Resistencia del conductor interno | 0,7 mΩ (a 10 A disipa 70 mW) |
| Ancho de banda | 500 kHz |
| Consumo | 11 a 14,5 mA |
| Tiempo de encendido hasta salida válida | 34 ms |
| Aislación | reforzada, 8 mm de línea de fuga y de aire |

La ventaja frente a un shunt es doble: no hay modo común (la salida ya está referida a masa lógica)
y el aislamiento galvánico lo hace inmune a los flancos del bus conmutado, que es exactamente el
problema que tiene un shunt en el lado alto con un puente H al lado.

### Dónde está conectado

`contacto NO del relé (K1.14) -> U3.IN- -> [conductor interno] -> U3.IN+ -> riel +12 V -> F3..F6 -> drivers`

Tres consecuencias:

1. **Mide únicamente la rama de tracción.** El LM2596 (y con él el ESP32 y los servos) cuelga del
   nodo A, aguas arriba del relé y del sensor. Lo que se lee es la suma de los cuatro motores más el
   consumo lógico de los cuatro drivers. Para el modelo a escala eso es incluso mejor que medir el
   total: el número que sale es directamente la corriente de tracción.
2. **El signo queda invertido.** La corriente entra por IN- y sale por IN+. La función de
   transferencia es `VOUT = IIN·S + VREF` con IIN positiva de IN+ a IN-. Con este cableado,
   descargar la batería hace **bajar** la salida desde 1,65 V:
   `I_traccion = (1,65 - Vout) / 0,1`
   Conviene confirmarlo con una carga conocida en el primer ensayo. Dar vuelta IN+/IN- no gana
   rango, porque el dispositivo es simétrico alrededor de 1,65 V.
3. **No hay medición por rama en la placa.** Con los pines IS de los BTS7960 sin usar, no se puede
   estimar el torque rueda por rueda desde el rover (desde el 27-sep hay una rueda medida con el
   ACS712, ver al final). Para el ensayo de caracterización `τ = K·(I - I0)` no
   molesta (ese ensayo va en banco con un motor por vez), pero sí impide validar el reparto de carga
   entre ruedas durante una trepada.

> **Nota de trazabilidad (16-sep-2026).** Hubo una contradicción entre documentos:
> `metodologia-modelo-escala` §3 afirmaba que el sensor medía el **consumo total de la PDB** y que
> por eso el Ensayo D quedaba invalidado por la contaminación de los servos. **Se resolvió a favor de
> este documento:** el TMCS1126 está en la rama conmutada, aguas abajo del relé, y los servos y el
> ESP32 cuelgan del nodo A, aguas arriba. Lo confirma la consecuencia arquitectónica ya documentada:
> al apretar la seta muere el bus de los drivers pero los servos y el ESP32 siguen alimentados; si
> los servos estuvieran en la rama medida, caerían con la seta. El análisis superado quedó archivado
> en [90-archivo/analisis-sensado-superado.md](../../90-archivo/analisis-sensado-superado.md).
>
> **Consecuencia práctica:** el Ensayo D es válido con el sensor de a bordo. El instrumento externo
> pasó de corrección obligatoria a mejora opcional, y el puente sobre la placa (cortar pista y
> reinsertar el sensor) es innecesario: ya está donde corresponde. Ver
> [50-ensayos/instrumentacion.md](../50-ensayos/instrumentacion.md).

Estado de cada afirmación del análisis superado:

| Afirmación de `metodologia` §3 | Estado |
|---|---|
| El sensor mide el total de la PDB | **Incorrecta.** Mide solo tracción |
| El Ensayo D queda invalidado | **No.** El Ensayo D es válido con el sensor de a bordo |
| Opción B: cortar pista y reinsertar el sensor | **Innecesaria.** Ya está donde corresponde |
| Opción C: instrumento externo obligatorio | **Degradada a opcional** |
| Opción A: Ensayo A fuera de la PDB | **Sigue vigente**, por su propio motivo: el motor se alimenta directo desde la fuente en continua pura |

**El único término parásito real** es el VCC lógico de los cuatro BTS7960, estimado en **10 a 30 mA**
(ver el presupuesto del riel de 3,3 V en
[arquitectura-electrica.md](arquitectura-electrica.md)). Es constante, así que se resta como línea de
base: se lee con el bus energizado y los motores parados, en el mismo tarado de cero que ya hay que
hacer al empezar cada sesión por la deriva térmica del Hall. No hay ningún otro consumo en la rama
medida.

### Rango de medición contra corriente de bloqueo (V8)

| Escenario | Corriente | Salida del sensor | ¿Entra en rango? |
|---|---|---|---|
| Marcha normal, 4 motores | 2 a 6 A | 1,45 a 1,05 V | Sí |
| Un motor bloqueado, tres girando | ~8 A | 0,85 V | Sí |
| Cuatro motores bloqueados | 22 A | saturaría a los 15,5 A | No |

El sensor satura alrededor de 15,5 A. Más que un error, es una decisión de diseño que conviene
asumir explícitamente: **el canal analógico cubre la operación normal y el canal digital OC cubre la
zona de falla**. Para eso hay que ajustar el umbral (V9). Alimentar el sensor con 5 V no ayuda,
porque el techo real lo pone la entrada del ADC del ESP32 en 3,3 V.

Resolución alcanzable con el ADC interno (ya reemplazado por el ADS1115 para ensayos: 0,63 mA por
cuenta con PGA ±2,048 V): el ADC de 12 bits sobre 3,3 V da 0,806 mV por escalón, o sea **8 mA por
escalón**. El ruido de entrada del sensor (150 uA/√Hz) filtrado a 1,6 kHz da unos 6 mA rms, del
mismo orden. El límite práctico va a ser la no linealidad conocida del ADC del ESP32, que hay que
calibrar por puntos.

### Cadena de acondicionamiento

| Bloque | Componentes | Función |
|---|---|---|
| Alimentación del sensor | +3,3 V -> C4 100 n -> FB1 (ferrita) -> C3 100 n -> VS | filtro en pi, aísla el sensor del ruido del riel lógico. Es la topología que recomienda el fabricante |
| Umbral de sobrecorriente | R3 4,7 k (de VS a VOC) + R4 47 k (de VOC a GND) + C5 1 u | divisor que fija el umbral |
| Salida al ADC | R15 1 k serie + C8 100 n a masa -> IO33 | pasabajos de **1,59 kHz** (τ = 100 us). Atenúa 22 dB a 20 kHz de PWM |
| VREF (pin 7) | libre, solo con una etiqueta local `Vref_CS` | ver nota |
| OC (pin 3) | R2 4,7 k a masa | ver V9 |

Sobre el R15 de 1 k: además de filtrar, aísla el capacitor de 100 nF de la salida del sensor. El
TMCS1126 admite como máximo 4,7 nF directamente en VOUT; sin esa resistencia serie el amplificador
de salida podría oscilar. Está bien resuelto.

Sobre VREF libre: es una **salida**, no una entrada, así que dejarla al aire es legal. Es una
oportunidad disponible: llevándola a un segundo canal de ADC y midiendo `Vout - Vref` en vez de
`Vout - 1,65 V` se cancelan el error de referencia, su deriva térmica y buena parte de la deriva del
propio ADC. Hoy no hay ningún ADC1 libre; queda como mejora.

### Umbral de sobrecorriente y pin OC (V9)

**Umbral.** La ecuación del fabricante es `VOC = S · IOC / 2,5`. Con el divisor actual:
`VOC = 3,3 × 47 / (47 + 4,7) = 3,0 V`, lo que da

`IOC = 2,5 × VOC / S = 2,5 × 3,0 / 0,1 = 75 A`

75 A no los alcanza este sistema, así que la protección no llegaría a dispararse nunca. Además el
fabricante pide que la resistencia inferior del divisor sea **menor a 10 k** (la impedancia de
entrada del pin VOC es 120 k y carga el divisor); R4 = 47 k queda fuera de esa guía y agrega un
error de umbral del orden del 30 %. Conviene medir la tensión real en VOC antes de dar el cálculo
por válido.

Ajuste propuesto, para un umbral de 25 A (por encima del bloqueo de 22 A, así no hay falsos
positivos):

`VOC = 0,1 × 25 / 2,5 = 1,0 V`

| Componente | Actual | Propuesto |
|---|---|---|
| R3 (VS a VOC) | 4,7 k | 11 k |
| R4 (VOC a GND) | 47 k | 4,7 k |
| VOC resultante | 3,0 V | 0,987 V |
| IOC resultante | 75 A | 24,7 A |

La histéresis de la variante de 100 mV/A es de 1,4 A, así que rearmaría a los 23,3 A. También
conviene subir C5 de 1 uF a 10 uF: el fabricante lo pide para estabilizar el umbral del comparador
en ambientes con flancos de modo común rápidos, que es justo el caso de un puente H.

**Pin OC.** Es una salida de colector abierto activa en bajo, conectada a masa a través de R2 =
4,7 k. Con un pull-down no puede subir nunca, así que la señal queda siempre baja y no va a ningún
lado. El fabricante dice que si no se usa se conecte a masa, así que no rompe nada.

**Mejora de alto valor:** hoy los `R_EN`/`L_EN` de los cuatro BTS7960 están atados permanentemente a
+3,3 V. Si en vez de eso ese nodo de enables se lleva a 3,3 V a través de una resistencia de pull-up
de 4,7 k y se le conecta el pin OC del TMCS1126, se obtiene:

- Corte de los cuatro puentes en 100 ns ante sobrecorriente, sin intervención del firmware.
- Rearme automático con histéresis.
- Cero GPIO consumidos.
- Y si además ese nodo se lleva a una entrada del ESP32 (cuando se libere una), se puede contar
  cuántas veces disparó.

Es una resistencia y una pista, y convierte una protección inactiva en la más rápida de la placa.

### Calibración

El TMCS1126 viene calibrado de fábrica (error de sensibilidad de 0,3 % en grado B), así que el error
dominante no va a ser el sensor sino el ADC del ESP32. Procedimiento mínimo:

1. Con el bus energizado y sin carga, leer `Vout` y guardarlo como cero real. No asumir 1,65 V.
2. Poner una carga conocida (lámpara de auto, resistor de potencia) medida con pinza amperométrica
   en 3 o 4 puntos entre 1 y 10 A, y ajustar una recta.
3. Repetir con los motores girando y PWM activo, para ver cuánto ripple queda después del filtro y
   decidir el promediado por software.
4. Verificar el cero a distintas temperaturas: la deriva de offset de esta variante son 30 uV/°C
   típicos, o sea 0,3 mA/°C referido a la entrada. Despreciable.

---

## ACS712 de respaldo (27-sep-2026)

Con el ADS1115 comprado quedan canales libres, y se suma el ACS712-30A que ya estaba disponible. Va
**a bordo**, no como instrumento externo, y se lee por el mismo bus I2C.

### Dónde va

En la **pata de motor de una rueda delantera**, entre la salida del BTS7960 y el motor. Ahí mide la
corriente real del motor, con signo, que es la que produce torque. Las dos razones:

1. El TMCS está del lado de la batería y con PWM lee `D · I_motor`, no `I_motor`. El ACS712 en la
   pata del motor valida la corrección por ciclo de trabajo. Ver
   [50-ensayos/instrumentacion.md](../50-ensayos/instrumentacion.md).
2. Puede quedar en la misma posición en el Ensayo A (pata del motor alimentada desde la fuente de
   banco) y en el Ensayo D, así su error de ganancia se cancela para esa rueda. El TMCS no puede
   estar en el Ensayo A.

Delantera porque en subida pierde carga normal y desliza primero. La alternativa, en la entrada de
batería, daba respaldo del total y consumo de servos por diferencia (útil para V3), pero con el mismo
sesgo por D que el TMCS.

### Conexión

| Punto | Detalle |
|---|---|
| Alimentación | 5 V propios: regulador lineal pequeño (78L05 o AMS1117-5.0) desde el riel "+5V" de la placa. Aunque ese riel esté en 5 V conviene el regulador: el LM2596 conmuta y el ACS712 es proporcional a su alimentación |
| Salida | a AIN1 del ADS1115, con 10 k en serie (limita la corriente si el ACS712 queda alimentado antes que el ADS) |
| Referencia de alimentación | divisor 1:2 de su 5 V a AIN2, para corregir cero y ganancia |
| Rango útil | con el ADS a 3,3 V, de −30 A a +12 A según el sentido. En la pata de un motor (±5,5 A en bloqueo) la salida va de 2,14 a 2,86 V |
| Sensibilidad | 66 mV/A, cero en la mitad de la alimentación |

El canal del TMCS va a AIN0 con un **cable desde el nodo Vout_CS** (pad de C8 o pin IO33): es un
agregado sin cortes, y el ESP32 sigue leyendo por IO33. Mapa completo de canales en
[50-ensayos/instrumentacion.md](../50-ensayos/instrumentacion.md). El ADS1115 comparte el I2C de J3
con el MPU6050 ([40-firmware/mapa-gpio.md](../40-firmware/mapa-gpio.md)).

### Qué no hace

- No mide el total: es una rueda. La extrapolación usa el total del TMCS corregido por D.
- No reemplaza a la protección por sobrecorriente.
- Su cero deriva más que el del TMCS: tarar al inicio de cada sesión y leer AIN2.

---

Los puntos V8, V9 y V11 y sus mediciones están resumidos en [30-pcb/pendientes-de-verificacion.md](../30-pcb/pendientes-de-verificacion.md). El uso de este sensor en los ensayos está en [50-ensayos/instrumentacion.md](../50-ensayos/instrumentacion.md).

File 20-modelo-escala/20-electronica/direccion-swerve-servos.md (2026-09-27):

---
titulo: Dirección swerve y riel de servos
estado: vigente
fecha: 2026-09-27
fuente: pcb-modelo-escala.md, sección direccion-swerve-servos
---

# Dirección swerve y servos

El modelo a escala pasó a ser **swerve, con un servo de dirección por rueda** (ya no es skid-steer).
Con eso el modelo sí valida la cinemática swerve, que era su laguna principal.

### Interfaz

Cuatro conectores Molex KK-254 de 3 vías, formato servo estándar: J12 (Servo1), J14 (Servo2), J13
(Servo3) y J17 (Servo4). Cada uno lleva GND, riel de servos y señal.

Dos señales salen de un conmutador analógico y no del GPIO directo: **Servo1 vía U4 (IO0)** y
**Servo3 vía U5 (IO15)**, porque IO0 e IO15 son pines de strapping que arrancan en alto. Servo2 (IO2)
y Servo4 (IO12) van directo, con pull-down de 10 k. El razonamiento completo está en
[40-firmware/mapa-gpio.md](../40-firmware/mapa-gpio.md); el pinout con huella y corriente, en
[30-pcb/mapa-conectores.md](../30-pcb/mapa-conectores.md).

Igual que con los drivers: la asociación servo N <-> rueda no está en el esquemático y hay que
fijarla.

### Margen del riel de servos (V3)

| Dato | Valor |
|---|---|
| Servos | 4, alimentados a 7,2 V según la nota del esquemático |
| Corriente de bloqueo por servo | 2,5 A (el PDF cita MG996R; confirmar el modelo real) |
| Demanda con los 4 bloqueados | 10 A |
| Demanda con los 4 moviéndose sin carga | 2 a 3,6 A |
| Capacidad del LM2596 (módulo comercial) | 3 A de pico nominal, 1,5 a 2 A continuos reales sin disipador |
| Reserva local | C1 = 1000 uF |

Cuánto aguanta el capacitor: para 10 A y aceptando 0,5 V de caída, `dt = C·dV/I = 1000u x 0,5 / 10`
= 50 microsegundos. O sea, sirve para los flancos de conmutación, no para sostener un bloqueo.

Como el ESP32 se alimenta del **mismo** nodo (pin 19, VIN, aguas arriba del PTC), en el caso de
bloqueo simultáneo el riel podría hundirse lo suficiente como para que el AMS1117 se quede sin
margen de caída (necesita del orden de 1,1 a 1,3 V por encima de 3,3 V) y el ESP32 se resetee. El
PTC no lo evita: actúa en segundos, el brownout en milisegundos.

**Ensayo que lo define:** trabar los cuatro servos a mano (o contra tope mecánico) con el
osciloscopio en el riel de 5V/7,2V y en 3V3, y ver cuánto cae y si el ESP32 sobrevive. Sumar un shunt
de 0,1 Ω en serie con el riel de servos (el TMCS1126 no lo ve) y repetir con arranque simultáneo
contra escalonado. Ese ensayo convierte esto de hipótesis en dato.

### Mitigaciones

De dónde sale el pico: un servo de hobby consume cerca de su corriente de bloqueo cada vez que la
consigna queda lejos de su posición, porque su control interno satura. Hay dos formas de atacarlo:
que los picos de los cuatro no coincidan (firmware) o que el ESP32 no dependa del nodo que se hunde
(hardware). **Solo el hardware resuelve V3**; el firmware baja la frecuencia del pico pero no cubre
un módulo trabado contra una piedra.

| # | Estrategia | Tipo | Costo sobre la placa | ¿Resuelve V3? |
|---|---|---|---|---|
| 1 | Arranque escalonado | firmware | ninguno | solo en el encendido, que es el peor caso |
| 2 | Rampa sincronizada | firmware | ninguno | baja los picos en marcha |
| 3 | Límite de 90° por módulo | firmware | ninguno | acorta cada pico |
| 4 | Reorientar con tracción detenida | firmware | ninguno | parcial, con contra |
| 5 | Convertidor propio para el ESP32 | hardware | corte y puente + módulo | **sí** |
| 6 | Alimentación separada para los servos | hardware | corte y puente, o solo mazo | **sí** |
| 7 | C1 de 1000 a 4700 uF | hardware | reemplazo de componente | no: ~235 us en vez de 50 us |

**Firmware** (implementar 1, 2 y 3 en cualquier caso):

1. **Arranque escalonado.** En el primer pulso válido el servo no sabe dónde está y va a máxima
   velocidad hasta la consigna. Habilitar los canales LEDC de a uno, con 150 a 200 ms entre cada
   uno. En el arranque la tracción está cortada, así que no hay costo cinemático.
2. **Rampa sincronizada en marcha.** En swerve los módulos tienen que orientarse juntos: desfasar
   los comandos hace que las ruedas se peleen y arrastren. En su lugar, la consigna avanza en rampa
   por debajo de la velocidad máxima del servo, así el error interno se mantiene chico y la
   corriente también. La duración la fija el módulo con más recorrido y cada módulo ajusta su
   velocidad para terminar en ese mismo tiempo. Actualizar a 50 Hz, un paso por período de PWM.
3. **Límite de 90°.** Si el giro pedido supera 90°, girar el complemento e invertir el sentido del
   motor de tracción. Reduce a la mitad el recorrido máximo.
4. **Reorientar con tracción detenida**, de a un módulo, solo para giros grandes (más de 15° a 20°
   de error). Contra: girar una rueda que no rueda pide más torque que girarla en marcha, sobre todo
   en arena. Baja la simultaneidad pero sube el pico de cada servo.

**Temporizador de bloqueo: no implementable tal como estaba planteado.** Cortar el PWM "si el servo
no llegó a destino" requiere saber dónde está, y un servo de hobby no informa su posición. El
TMCS1126 tampoco ve el riel de servos. Alternativas reales:

- Corte por tiempo, a ciegas: no distingue un servo trabado de uno lento.
- Servos con realimentación (por ejemplo, de bus serie, que informan posición y carga): cuesta
  pines y un UART.
- Sensado de corriente en el riel de servos: hoy no queda ningún ADC1 libre.

**Hardware** (se decide con el resultado de V3):

5. **Convertidor propio para el ESP32**, alimentado desde el nodo A. Aísla la carga chica (~250 mA),
   así que el cableado es simple. Los servos pueden seguir hundiendo su riel y perder torque, pero
   el ESP32 sobrevive.
6. **Alimentación separada para los servos**: una 2S LiPo dedicada (7,4 V, ESR bajo del orden de
   25 mΩ) o un convertidor dedicado. Solo se comparte GND, en el punto estrella. Libera además al
   LM2596 para quedar en 5 V, lo que baja la disipación del AMS1117. Se puede hacer **sin tocar la
   placa** con un mazo en Y: señal y GND salen de J12 a J17 y el positivo viene del convertidor
   externo, con conectores con traba. En ese caso F2 deja de proteger ese riel y hace falta un
   fusible propio a la salida del convertidor.
7. Subir C1 a 4700 uF solo ayuda con los flancos de arranque; no sostiene un bloqueo.

Orden sugerido: firmware 1, 2 y 3 ya; ensayo de V3; si el ESP32 se resetea con los cuatro trabados,
opción 6 con mazo en Y.

### F2: un solo PTC para los cuatro servos

El PDF planificaba 4 PTC individuales; la placa tiene uno solo (F2) en serie con todo el riel.

Trade-off explícito:
- **A favor**: menos componentes, menos área, menos caída acumulada.
- **En contra**: se pierde selectividad. Un servo trabado corta el riel de los cuatro. Con 4 PTC, el
  que se traba se aísla y los otros tres siguen funcionando.

Además, no existen PTC radiales chicos que sostengan 10 A: los valores prácticos llegan a 3 a 5 A de
corriente de mantenimiento. Con uno de 3 A, un movimiento simultáneo de los cuatro servos queda
cerca del disparo; con 5 A, no protege contra dos servos trabados.

**El valor de F2 no está definido en el esquemático.** La huella asignada es de varistor de disco de
9 mm: un PTC radial entra físicamente, pero conviene corregir la huella para que el BOM no confunda.

### Estado en el arranque

| Servo | Pin | Estado durante el boot | Riesgo |
|---|---|---|---|
| Servo1 | IO0 vía U4 | 3,3 V continuos | Sin pulso PWM válido el servo no se mueve |
| Servo2 | IO2 con pull-down | 0 V | Ninguno |
| Servo3 | IO15 vía U5 | 3,3 V continuos | Ídem Servo1 |
| Servo4 | IO12 con pull-down | 0 V | Ninguno |

Los cuatro casos son seguros. La única salvedad es que un nivel continuo en alto puede producir una
contracción mecánica leve en algunos servos digitales al energizar.

---

El punto V3 y su medición están resumidos en [30-pcb/pendientes-de-verificacion.md](../30-pcb/pendientes-de-verificacion.md).

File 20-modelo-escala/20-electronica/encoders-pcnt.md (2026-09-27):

---
titulo: Encoders en cuadratura y periférico PCNT
estado: vigente
fecha: 2026-09-16
fuente: pcb-modelo-escala.md, sección encoders-pcnt
---

# Encoders y PCNT

Validado: se probó un encoder y funcionó correctamente.

### Interfaz física

Cuatro conectores idénticos de 4 vías, Molex KK-254 vertical, uno por rueda: J9 (FR), J16 (FL),
J18 (RL) y J8 (RR). El pinout completo, con huella y corriente nominal, está en
[30-pcb/mapa-conectores.md](../30-pcb/mapa-conectores.md); la asignación de GPIO a cada canal, en
[40-firmware/mapa-gpio.md](../40-firmware/mapa-gpio.md).

**Los encoders se alimentan con 3,3 V**, no con 5 V. Esto resuelve de raíz el riesgo de sobretensión
en IO34..IO39 que estaba abierto: como el encoder del CQR37D12V64EN-I acepta de 3,3 a 24 V, al
alimentarlo con 3,3 V la salida no puede superar 3,3 V, tenga o no pull-up interno el módulo.
Si algún módulo trae pull-up interno a VCC, queda en paralelo con el de la placa y el equivalente
baja (4,7 k // 10 k = 3,2 k): no es un problema, pero sí una diferencia de tiempos entre canales.

### Acondicionamiento

Cada canal tiene **un pull-up de 4,7 k a 3,3 V** (R1, R7, R8, R9, R10, R11, R12, R13) y nada más.
No hay resistencia serie ni capacitor. Esto es obligatorio, no opcional: IO34, IO35, IO36 e IO39
son de solo entrada y **no tienen pull-up ni pull-down internos**, así que sin estas resistencias
esas cuatro líneas quedarían flotando.

Verificación de que 4,7 k alcanza:

- Capacidad del cable: ~100 pF/m. Con 60 cm de cable más la entrada del ESP32, del orden de 70 pF.
- Constante de subida: 4,7 k x 70 pF = **0,33 us**.
- Frecuencia máxima por canal, con el motor CQRobot a 120 rpm de salida, 90:1 y 64 CPR en el eje
  del motor: 10800 rpm de motor = 180 rev/s, 16 pulsos por vuelta y por canal -> **2,9 kHz**.
  Período de 345 us, y el evento más corto (flanco de A a flanco de B en cuadratura) son **86 us**.

0,33 us contra 86 us: tres órdenes de magnitud de margen. El pull-up de 4,7 k está bien elegido para
velocidad. Lo que se pierde frente a un valor más bajo es inmunidad al ruido. Si aparecen cuentas
espurias con los motores girando, la secuencia de corrección es:

1. Activar el **filtro de glitch del periférico PCNT** (es gratis, no lleva componentes). Con 100 a
   200 ciclos de APB (1,25 a 2,5 us) se filtra ruido sin tocar los 86 us reales. El máximo son 1023
   ciclos = 12,8 us, así que hay lugar de sobra.
2. Recién si eso no alcanza, bajar los pull-ups a 2,2 k.
3. Como último recurso, un RC (2,2 k serie + 1 nF). **No usar 10 nF**: con esas impedancias destruye
   el flanco.

### Uso del periférico PCNT

El ESP32 tiene 8 unidades PCNT. Se usan 4, una por rueda, con los dos canales de cada unidad
configurados para decodificación en cuadratura x4 (una señal como pulso, la otra como control).

Cuentas por vuelta de rueda: 64 CPR en el eje del motor x 90 de reducción = **5760 cuentas por
vuelta de salida**.

Punto a resolver en firmware: **el contador del PCNT es de 16 bits con signo** (±32767). A 120 rpm
de salida son 11520 cuentas/s, o sea que **desborda cada 2,8 segundos**. Hay que usar los eventos de
límite del hardware y acumular en una variable de 32 o 64 bits. Si se lee el contador por sondeo sin
manejar el desborde, la medición de velocidad se rompe silenciosamente.

### Pendientes

- Repetir la prueba en los cuatro canales, no solo en el que ya se validó.
- Medir el consumo real de los cuatro encoders a 3,3 V (entra directo en el presupuesto del AMS1117).
- Definir el sentido positivo de cuenta de cada rueda y dejarlo escrito (las dos ruedas de un lado
  giran al revés que las del otro para avanzar).
- Cablear A/B como par trenzado con su propio GND de retorno, lejos de los cables de motor.

---

Conectores en [30-pcb/mapa-conectores.md](../30-pcb/mapa-conectores.md); GPIO en [40-firmware/mapa-gpio.md](../40-firmware/mapa-gpio.md).

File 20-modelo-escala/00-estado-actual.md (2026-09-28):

---
titulo: Modelo a escala — estado actual de la placa
estado: vigente
fecha: 2026-09-28
fuente: pcb-modelo-escala.md (encabezado, estado de validación y cambios respecto del PDF)
---

# PCB del modelo a escala (PDB + control) — estado actual

Documentación derivada del esquemático de KiCad, que es la fuente de verdad. Donde el PDF de
planificación del 17-ago-2026 dice otra cosa, manda el `.sch` y se aclara la diferencia.

- Fuente primaria: `PCB_modelo.kicad_sch` (KiCad 9.0, hoja A3).
- Fuente secundaria: `Modelo_a_escala_ROVER.pdf` (17-ago-2026) — **obsoleto donde contradiga al
  `.sch`**.
- Los archivos de KiCad están en [`pcb_V1/`](../pcb_V1/) para descargar. Lo que salió de analizarlos
  está en estos markdown.

---

## Estado de validación

La placa ya tuvo pruebas parciales con resultado correcto. Se probó un encoder y un puente H de cada
unidad, y funcionaron. El testeo completo está en curso.

| Bloque | Estado | Detalle |
|---|---|---|
| Arquitectura eléctrica y rieles | documentado, sin medir | [20-electronica/arquitectura-electrica.md](20-electronica/arquitectura-electrica.md) |
| Encoders y PCNT | **un canal validado**, faltan tres | [20-electronica/encoders-pcnt.md](20-electronica/encoders-pcnt.md) |
| Drivers BTS7960 | **un puente H de cada unidad validado** | [20-electronica/drivers-bts7960.md](20-electronica/drivers-bts7960.md) |
| Dirección swerve y servos | sin ensayar (V3 abierto) | [20-electronica/direccion-swerve-servos.md](20-electronica/direccion-swerve-servos.md) |
| Sensado de corriente | TMCS montado, sin calibrar. ADS1115 comprado y ACS712 a sumar en una rueda | [20-electronica/sensado-corriente.md](20-electronica/sensado-corriente.md) |
| Protecciones y desacople | montado, Q1 puenteado, cuatro puntos abiertos | [20-electronica/protecciones-desacople.md](20-electronica/protecciones-desacople.md) |
| Mapa de GPIO y arranque seguro | documentado, V1 mitigado con pull-up y sin verificar | [40-firmware/mapa-gpio.md](40-firmware/mapa-gpio.md) |

---

## Cambios ya confirmados respecto del PDF

- El **ACS712-30A quedó cancelado como sensor de placa** (vuelve como respaldo a bordo desde el
  27-sep, ver abajo). Se reemplaza por un **TMCS1126B4** midiendo **corriente total
  de tracción**, no por rama.
- **No se usa el sensado de corriente de los módulos BTS7960** (los pines `IS` quedan sin cablear).
- El **pinout del ESP32 cambió** respecto de la tabla del PDF (ver
  [40-firmware/mapa-gpio.md](40-firmware/mapa-gpio.md)).
- Los **pull-down de 10 k en las 8 líneas PWM no existen** en la placa. Se reemplazaron por una
  estrategia distinta con conmutadores analógicos NLAS4157.
- Los **4 PTC individuales de servo** se redujeron a **un solo PTC** para todo el riel.
- El MOSFET de polaridad inversa es **IRF9540N**, no IRF4905. **Desde el 27-sep está puenteado**: la
  polaridad se protege con un conector de un solo sentido.

## Cambios del 27-sep-2026, posteriores al `.sch`

- **Pull-up en L_PWM_4** (V1): componente agregado. Falta verificar con osciloscopio.
- **Q1 puenteado** (V2 no aplica).
- **ACS712-30A vuelve**, no como sensor de placa sino como segundo sensor a bordo en la pata de motor
  de una rueda delantera, leído por un **ADS1115** en el bus I2C junto al TMCS.
- **Ruedas del modelo: 150 mm de diámetro**, no 102 mm. Abre la decisión de escala en
  [10-metodologia-similitud.md](10-metodologia-similitud.md) §0.

Los motivos de cada descarte están en
[00-contexto/04-decisiones-descartadas.md](../00-contexto/04-decisiones-descartadas.md).

---

## Los puntos V1 a V12

A lo largo de la documentación hay referencias del tipo (V1), (V2)... Son puntos de análisis de
escritorio que **quedan pendientes de confirmar midiendo, no defectos verificados**. Varios pueden
descartarse con una medición de dos minutos y algunos ya podrían estar descartados por las pruebas
hechas.

Están resumidos, con su método de confirmación y su sección de discusión, en
[30-pcb/pendientes-de-verificacion.md](30-pcb/pendientes-de-verificacion.md).

**Cualquier propuesta de cambio sobre esta placa tiene que decir si es un corte y un puente, un
componente a reemplazar o un rediseño.** La placa ya está fabricada y soldada: el costo de la
corrección importa tanto como su corrección técnica.

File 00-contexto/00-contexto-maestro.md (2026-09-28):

---
titulo: Contexto maestro — Rover ERC, subsistema de Electrónica y Potencia
owner: Matías Bélico
version: 2.1
estado: vigente
fecha: 2026-09-27
fuente: 00-contexto-maestro.md (fuente original en 90-archivo/fuentes-originales/), reducido a índice de estado
alcance: subsistema de potencia y electrónica
proposito: documento raíz del repo. Estado, conflictos abiertos y próximos pasos. El detalle técnico vive en los archivos que este índice referencia.
---

# Contexto maestro — Rover ERC

Este es el documento raíz. **No tiene datos técnicos propios, salvo los próximos pasos (§7).** Si un
número aparece acá y en un archivo de detalle, manda el detalle. Acá está el estado, lo que todavía no
cierra y dónde buscar.

---

## 1. Qué es el proyecto

**Competencia:** European Rover Challenge (ERC).
**Equipo:** IEEE ITBA I+D.
**Subsistema:** Electrónica y Potencia.

Dos frentes en paralelo:

| Frente | Propósito | Estado |
|---|---|---|
| **Rover final** | El vehículo que compite. 40 kg, bus de 24 V, swerve de 4 ruedas. | Arquitectura mecánica cerrada. Sin motor elegido. |
| **Modelo a escala** | Instrumento de medición, no maqueta. Mide torque real en piso duro y arena y extrapola al rover final. | PCB fabricada y soldada, con validación parcial. Sin ensayos. |

El modelo existe para cerrar la especificación de motores sin comprar motores de tamaño real a
ciegas. Esa es su única razón de ser, y todo lo que se decide sobre él se juzga contra eso.

---

## 2. Marco

| Tema | Resumen | Detalle |
|---|---|---|
| Alcance | Batería, potencia, control de motores, protecciones, sensado, firmware y telemetría. Mecánica entra solo como interfaz; λ entra como dato | [01-alcance-y-fronteras.md](01-alcance-y-fronteras.md) |
| Reglas no negociables | COTS primero, star grounding, silicona AWG, conectores con traba, E-Stop y fusibles | [02-filosofia-de-diseno.md](02-filosofia-de-diseno.md) |
| Descartados | Qué se evaluó y no quedó, con el motivo | [04-decisiones-descartadas.md](04-decisiones-descartadas.md) |
| Principios transversales | Trece reglas ganadas que aplican más allá de su caso | [05-principios-transversales.md](05-principios-transversales.md) |

---

## 3. Conflictos abiertos

Tres puntos bloquean decisiones hoy. Ninguno se resuelve escribiendo: se resuelven midiendo o
preguntando.

> **Resuelto (16-sep): qué mide el TMCS1126.** Mide **solo la rama de tracción**. La afirmación de
> que medía el total de la PDB quedó superada. El Ensayo D es válido con el sensor de a bordo.

| # | Conflicto | Qué bloquea | Cómo se cierra |
|---|---|---|---|
| 1 | Diámetro de rueda del rover real: circulan tres valores | Cálculos de torque y reimpresión de ruedas del modelo | Consulta a Mecánica |
| 2 | μ / pendiente: el μ declarado no alcanza para 30° | Elección del motor grande | Ensayo de ángulo de deslizamiento |
| 3 | Torque pedido inconsistente con el techo de tracción | Dimensionamiento continuo contra transitorio | Ya tiene lectura propuesta |

Desarrollo y consulta consolidada a Mecánica en
[03-conflictos-abiertos.md](03-conflictos-abiertos.md).

---

## 4. Rover final — estado

| Tema | Estado | Detalle |
|---|---|---|
| Parámetros y requisitos de motor | Vigentes pero sujetos a los conflictos 1 a 3 | [requisitos-motor.md](../10-rover-final/10-locomocion/requisitos-motor.md) |
| Motor | **Sin candidato.** El último quedó descartado | [candidatos-motores.md](../10-rover-final/10-locomocion/candidatos-motores.md) |
| Presupuesto de corriente | Tracción calculada. Falta brazo, cómputo, comunicaciones y ciencia | [presupuesto-corriente.md](../10-rover-final/20-potencia/presupuesto-corriente.md) |
| Cableado y protecciones | Preliminar, bloqueado por la elección del motor | [cableado-y-protecciones.md](../10-rover-final/20-potencia/cableado-y-protecciones.md) |

---

## 5. Modelo a escala — estado

| Tema | Estado | Detalle |
|---|---|---|
| Escala, motor y qué valida el modelo | **Abierta:** las ruedas miden 150 mm y no corresponden a ~5,5 kg. Decidir reimprimir (recomendado) o lastrar | [10-metodologia-similitud.md](../20-modelo-escala/10-metodologia-similitud.md) §0 |
| PCB | Fabricada y soldada. Validación parcial correcta. Q1 puenteado, pull-up en L_PWM_4. Testeo completo en curso | [00-estado-actual.md](../20-modelo-escala/00-estado-actual.md) |
| Puntos V1 a V12 | Hipótesis de escritorio pendientes de medir, no defectos. V1 mitigado sin verificar, V2 no aplica, V3 en pausa | [pendientes-de-verificacion.md](../20-modelo-escala/30-pcb/pendientes-de-verificacion.md) |
| Ensayos | Plan rev. 2.0 (reemplaza al protocolo rev. 1.0). Ninguno corrido | [plan-de-ensayos.md](../20-modelo-escala/50-ensayos/plan-de-ensayos.md) |
| Pinout | Fuente única de verdad | [mapa-gpio.md](../20-modelo-escala/40-firmware/mapa-gpio.md) |

---

## 6. Instrumentación de ensayos — decisiones cerradas

- **ADS1115** para leer el TMCS1126: el conversor interno del ESP32 es el eslabón débil. **Comprado.**
- **ACS712 a bordo en la pata de motor de una rueda delantera**, leído por el mismo ADS1115: respaldo
  y validación. No es un sensor por motor para la extrapolación.
- **Corrección por ciclo de trabajo:** con PWM el TMCS mide corriente de batería (≈ D · I_motor). Se
  registra D por rueda y se corrige.
- **Tiro en barra como método primario**, corriente como canal redundante, en simultáneo. Coinciden
  en piso duro; en arena la diferencia es la resistencia de compactación. Balanza de gancho: la presta
  la facultad.
- **Instrumento externo:** no se construye por ahora.
- **Sin convertidor regulado:** batería de plomo directo al bus, lazo cerrado de velocidad y registro
  de tensión y D.

Detalle en [instrumentacion.md](../20-modelo-escala/50-ensayos/instrumentacion.md) y
[sensado-corriente.md](../20-modelo-escala/20-electronica/sensado-corriente.md).

---

## 7. Próximos pasos

En orden de valor por esfuerzo.

| # | Acción | Costo | Desbloquea | Bloqueado por |
|---|---|---|---|---|
| 1 | **Ensayo 0: ángulo de deslizamiento** en piso duro | 0 | El μ real, que hoy bloquea la elección del motor grande, y el ángulo del Ensayo D | superficie y rampa (Mecánica) |
| 2 | **Consulta única a Mecánica**: diámetro, μ, naturaleza de los 30°, más los pedidos de ensayo | 1 mensaje | λ, requisitos de torque, decisión de ruedas | conviene hacer #1 antes |
| 3 | **Decidir rueda o lastre** (ruedas de 150 mm) | 0 | Escala del modelo, Ensayo D | reunión de líderes, #2 |
| 4 | **Pesar el modelo completo** con todo montado | 0 | λ definitivo | nada |
| 5 | **Cablear ADS1115 y ACS712** y calibrar TMCS y ACS712 contra multímetro | ~2 USD | Cadena de medición; cierra V9, V11 y la sensibilidad del TMCS | nada |
| 6 | Verificar V1 con osciloscopio (pull-up ya soldado) | 0 | Seguridad de la placa | nada |
| 7 | **Ensayo A** en los 4 motores, con ACS712 y multímetro en serie | 0 | K, I₀ y R | #5 |
| 8 | **Ensayo A'** (cadena bajo modulación), B y C | 0 | Corrección por D validada, K verificada, encoders | #7 |
| 9 | **D0**, ensayo de método en piso duro | 0 | Método del Ensayo D depurado | #1, #5, #8 |
| 10 | **Reimprimir ruedas** al diámetro correcto, y medirlas con calibre | — | Cierra la escala | **#2, #3 y #4** |
| 11 | Medir altura del CM y comparar con 0,3464·λ | 0 | Validez de conclusiones de estabilidad | #10 |
| 12 | Buscar motor de reemplazo del 42RBL04A | — | Rover final | #1 y #2 |
| 13 | Presupuesto de corriente de los otros subsistemas | — | Batería y PDB del rover final | otros subsistemas |

Hechos desde la versión anterior: ADS1115 comprado; balanza de gancho conseguida (la presta la
facultad); Q1 puenteado (V2 no aplica); pull-up en L_PWM_4 para V1. Descartado: instrumento externo
por ahora.

Casi todo lo que va de #4 a #9 no depende de nadie más y cuesta menos de tres dólares. Los pasos que
cuestan plata o tiempo de impresión (#10 y #12) dependen de que Mecánica responda.

Plan de ensayos del modelo en
[plan-de-ensayos.md](../20-modelo-escala/50-ensayos/plan-de-ensayos.md). Versión para compartir con
Mecánica: `Plan_Ensayos_Modelo_Rover_ERC_rev2.docx` en `Desktop\Rover` (fuera del repo).

---

## 8. Mapa del repositorio

| Carpeta | Qué contiene |
|---|---|
| `00-contexto/` | Este documento, alcance, filosofía, conflictos, descartados, principios |
| `10-rover-final/` | Requisitos de motor, candidatos, presupuesto de corriente, cableado |
| `20-modelo-escala/` | Escala, electrónica, PCB, firmware, ensayos |
| `30-componentes/` | Ficha por componente y enlaces a hojas de datos |
| `40-proveedores-costos/` | Proveedores y costos de importación |
| `90-archivo/` | Versiones superadas y ramas muertas. **No usar como fuente** |

Índice archivo por archivo y convenciones en el [README del repo](../README.md).

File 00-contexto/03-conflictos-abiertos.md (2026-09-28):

---
titulo: Conflictos abiertos con Mecánica
estado: vigente
fecha: 2026-09-27
fuente: 00-contexto-maestro.md §4 + requisitos-motor-rover-real.md (conflicto μ/pendiente)
---

# Conflictos abiertos

Los tres puntos que hoy bloquean decisiones. Ninguno se resuelve escribiendo: se resuelven midiendo
o preguntando.

> **Resuelto (16-sep): qué mide el TMCS1126.** Hubo una contradicción entre documentos. Vale
> `pcb-modelo-escala`: el sensor mide **solo la rama de tracción**. La afirmación de
> `metodologia-modelo-escala` §3 de que medía el consumo total de la PDB es incorrecta y queda
> superada. El análisis superado está en
> [90-archivo/analisis-sensado-superado.md](../90-archivo/analisis-sensado-superado.md) y el montaje
> real en
> [sensado-corriente.md](../20-modelo-escala/20-electronica/sensado-corriente.md).

---

## 1. Diámetro de rueda del rover real — tres valores en circulación

| Fuente | Diámetro |
|---|---|
| Hoja 1 de cálculos de Mecánica | 0,35 m |
| Hoja 2 de cálculos de Mecánica | 0,28 m |
| Informe mecánico jul-2026 | 0,30 m (declarado definitivo) |

El torque escala lineal con R y la velocidad angular inversamente: entre 0,28 y 0,35 hay ~20% de
diferencia en ambos requisitos. **Todos los cálculos del subsistema de potencia deben rehacerse con
el diámetro final una vez confirmado.**

Cada valor arrastra su propio par de cálculos en los documentos de Mecánica: la hoja 1 calculó ω y T
con R = 0,175 m, y la hoja 2 con R = 0,14 m. No es que haya un cálculo con tres resultados, son tres
cálculos consistentes cada uno con su hipótesis.

**Consecuencia sobre el modelo:** λ se define por el cociente de diámetros de rueda. Con los tres
valores el diámetro correcto del modelo cambia; la tabla de equivalencias está en
[10-metodologia-similitud.md](../20-modelo-escala/10-metodologia-similitud.md) §3.

**Actualización (27-sep-2026):** las ruedas actuales del modelo miden **150 mm**, no 102. Con 5,5 kg
eso deja la presión de contacto entre 48 y 75 % de la correcta según el diámetro real: error del lado
inseguro. Hay que decidir entre reimprimir ruedas (recomendado) o lastrar a 7,4–11,5 kg, y las dos
opciones dependen de este mismo dato. Ver
[10-metodologia-similitud.md](../20-modelo-escala/10-metodologia-similitud.md) §0.

**Estado: pendiente de consulta a Mecánica.** Bloquea la reimpresión de ruedas. No mandar a imprimir
antes de tener la respuesta: son 26 mm de diferencia entre extremos y la impresión no es gratis en
tiempo.

---

## 2. Conflicto μ / pendiente

No deslizar en pendiente exige μ ≥ tan(θ). Para 30° hace falta μ ≥ 0,577; el informe declara μ = 0,4,
que topea la pendiente trepable en arctan(0,4) ≈ 21,8°.

Es estructural, no un error de cuenta: más torque de motor no lo resuelve.

Mientras no se responda, el requisito de 11–17 N·m se toma como válido, pero el límite sin deslizar
del informe (5,214 N·m) queda inconsistente con él. Es el mismo choque que aparece en el conflicto 3,
visto desde la hoja de Mecánica en lugar de desde el techo de tracción.

**Se cierra empíricamente y gratis:** ensayo de ángulo de deslizamiento con el modelo. Se sube la
rampa hasta que patina, y μ = tan(θ_deslizamiento). El coeficiente es adimensional: no escala, no
tiene λ, no tiene error de extrapolación. El valor medido en el modelo es directamente el del rover
real, con la condición de que rueda y superficie sean del mismo material.

Es el ensayo de mayor valor por unidad de esfuerzo de todo el programa. Además vuelve la pregunta a
Mecánica mucho más fácil de responder: en vez de pedirles un número que quizá no midieron, se les
lleva uno medido para que lo confirmen o lo discutan.

Procedimiento en
[50-ensayos/plan-de-ensayos.md](../20-modelo-escala/50-ensayos/plan-de-ensayos.md).

---

## 3. Requisito de torque inconsistente con el techo de tracción

Los requisitos vigentes de Mecánica piden 11–17 N·m nominales por rueda. El techo de tracción en la
peor pendiente sostenible, calculado en
[presupuesto-corriente.md](../10-rover-final/20-potencia/presupuesto-corriente.md), es menos de la
mitad. Están en dos órdenes distintos de la misma magnitud.

La lectura correcta: los 11–17 N·m son de trepado de obstáculo (evento de segundos, torque alto y
velocidad baja) y el techo de tracción es el continuo sostenible. No son el mismo requisito y no deben
dimensionar la misma cosa. Ver
[20-potencia/presupuesto-corriente.md](../10-rover-final/20-potencia/presupuesto-corriente.md).

El requisito completo, con la nota del cálculo corregido de potencia, está en
[10-locomocion/requisitos-motor.md](../10-rover-final/10-locomocion/requisitos-motor.md).

---

## 4. Consulta pendiente a Mecánica

Los tres conflictos se responden con las mismas personas. Conviene una sola consulta y no tres
mensajes sueltos:

1. **¿Cuál es el diámetro de rueda definitivo?** Hay 0,28, 0,30 y 0,35 m circulando en tres
   documentos distintos. Afecta todos los cálculos de torque del subsistema y el diámetro de las
   ruedas del modelo a escala.
2. **¿Cuál es el μ real, medido o asumido, para el terreno de la competencia?** Con μ = 0,4 la
   pendiente trepable topea en 21,8°, no en 30°.
3. **¿Los 30° son una pendiente sostenida o un obstáculo puntual?** Si es puntual se supera con
   inercia y el criterio de no deslizamiento no aplica igual, lo que cambia el requisito de continuo.

Conviene hacer primero el ensayo de ángulo de deslizamiento (conflicto 2) y llevar ese número a la
consulta.

A esas tres preguntas se suman los pedidos de los ensayos (decisión de rueda o lastre, material de la
rueda, superficie, rampa, anclaje, lecho de arena, definición de torque umbral), listados en
[plan-de-ensayos.md](../20-modelo-escala/50-ensayos/plan-de-ensayos.md) y en el docx del plan rev. 2.0.

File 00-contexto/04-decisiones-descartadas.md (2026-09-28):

---
titulo: Decisiones descartadas
estado: vigente
fecha: 2026-09-27
fuente: consolidado de los cuatro documentos (contexto maestro, pcb-modelo-escala, metodologia-modelo-escala, requisitos-motor)
---

# Decisiones descartadas

Registro de lo que se evaluó y no quedó, con el motivo. Sirve para no volver a proponer lo mismo
dentro de tres meses. No son ADR formales: es una tabla.

Dos filas tienen el motivo pendiente de registrar. Están marcadas como tales y no se inventa la
razón.

| Qué | Motivo |
|---|---|
| 6WD | (motivo pendiente de registrar) |
| Rocker-bogie | (motivo pendiente de registrar) |
| Skid-steer en el modelo | Se pasó a swerve, con un servo de dirección por rueda |
| N20 100 rpm | RPM y torque insuficientes |
| GA25-370 1/46.8 | Hoja de datos inconsistente, ventana de masa vacía |
| NEMA 17 + AS5600 | Corriente de fase constante: la corriente deja de ser proxy de torque |
| GoBILDA Saturn 5304-8002-0188 | Térmicamente válido pero sobredimensionado |
| 42RBL04A | El proveedor nunca respondió; interfaz del controlador nunca confirmada |
| Reducción 1/49 | 98% del torque nominal en continuo, sin margen térmico |
| λ = 0,34 / 4,6 kg | Superado por la masa real de 5,5 kg |
| INA226 | No cubre el pico de 5,5 A; no se consiguen módulos de más de 5 A en Argentina |
| ACS712-30A como sensor de placa | Reemplazado por TMCS1126B4 (Hall aislado). **27-sep: vuelve con otro rol**, como segundo sensor a bordo en la pata de motor de una rueda, leído por ADS1115: respaldo y validación de la corrección por ciclo de trabajo. No revierte el descarte como sensor principal |
| Sensor de corriente por motor | El error de ganancia se cancela con un solo sensor |
| Pines IS de los BTS7960 | Sin cablear: sin medición por rueda. **En revisión (27-sep):** a lo sumo un canal experimental |
| 4 PTC de servo | Reducidos a uno solo para todo el riel |
| IRF4905 | Reemplazado por IRF9540N en la placa |
| Protección de polaridad con MOSFET (Q1) | Puenteado el 27-sep: se usa un conector de un solo sentido. Elimina calor y caída; pierde protección contra conectar con cables sueltos |
| Convertidor a 12,0 V regulados para el modelo | El modelo usa plomo 12 V directo al bus; se compensa con lazo cerrado de velocidad y registro de tensión y D |
| Instrumento externo con segundo microcontrolador | No se construye por ahora: ADS1115 y ACS712 a bordo, en el mismo I2C |
| Capacitor de 10 nF en encoder | Destruye el flanco con esas impedancias |
| TVS de 12,8 V de standoff | Avalancha continua con la batería a 13,8–14,4 V |
| Bajar el modelo a 4,6 kg | Difícil, no vale la pena: se ajusta el diámetro de rueda |
| Corregir el desfasaje de λ a mano | El término de compactación no tiene corrección exacta sin caracterizar la arena |

---

## Dónde se discute cada descarte

| Fila | Discusión completa |
|---|---|
| Motores del rover final (42RBL04A, reducciones, candidatos) | [candidatos-motores.md](../10-rover-final/10-locomocion/candidatos-motores.md) |
| Escala (λ = 0,34, bajar a 4,6 kg, corregir a mano) | [10-metodologia-similitud.md](../20-modelo-escala/10-metodologia-similitud.md) |
| Cadena de medición (INA226, sensor por motor, ACS712) | [instrumentacion.md](../20-modelo-escala/50-ensayos/instrumentacion.md) y [sensado-corriente.md](../20-modelo-escala/20-electronica/sensado-corriente.md) |
| Pines IS, pull-down de PWM | [drivers-bts7960.md](../20-modelo-escala/20-electronica/drivers-bts7960.md) |
| 4 PTC de servo | [direccion-swerve-servos.md](../20-modelo-escala/20-electronica/direccion-swerve-servos.md) |
| IRF4905, Q1 puenteado y TVS de 12,8 V | [protecciones-desacople.md](../20-modelo-escala/20-electronica/protecciones-desacople.md) |
| Convertidor regulado e instrumento externo | [plan-de-ensayos.md](../20-modelo-escala/50-ensayos/plan-de-ensayos.md) y [instrumentacion.md](../20-modelo-escala/50-ensayos/instrumentacion.md) |
| Capacitor de 10 nF en encoder | [encoders-pcnt.md](../20-modelo-escala/20-electronica/encoders-pcnt.md) |
| Skid-steer en el modelo | [10-metodologia-similitud.md](../20-modelo-escala/10-metodologia-similitud.md) §8 |

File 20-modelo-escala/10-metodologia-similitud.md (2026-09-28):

---
titulo: Metodología de similitud y escala del modelo
estado: vigente
fecha: 2026-09-27
fuente: metodologia-modelo-escala-y-presupuesto-pdb.md §4, riesgos de escala de §5 y anexo de constantes; dato de rueda de 150 mm (27-sep-2026)
---

# Revisión de escala por la masa real de 5,5 kg

**La masa real de 5,5 kg no saca al modelo de rango: mejora el margen.** Pero obliga a llevar el
diámetro de rueda del modelo al valor que corresponde a esa masa (111 mm con un rover real de 0,30 m).

> **Nota de estado (27-sep-2026):** las ruedas del modelo miden **150 mm**, no 102 mm como suponía
> este archivo. La escala queda **abierta** hasta decidir rueda o lastre (§0). Los valores con
> λ = 0,371 siguen siendo los correctos **si se reimprimen las ruedas**. El protocolo rev. 1.0
> (λ = 0,34) quedó reemplazado por el plan rev. 2.0: ver
> [50-ensayos/plan-de-ensayos.md](50-ensayos/plan-de-ensayos.md).

---

## 0. Ruedas de 150 mm: decisión pendiente

λ se define por el diámetro de rueda (§3). Con ruedas de 150 mm la escala geométrica y la másica no
coinciden:

| Diámetro del rover real | λ por la rueda (150 mm) | Masa coherente (40·λ²) | Presión de contacto con 5,5 kg |
|---|---|---|---|
| 0,28 m | 0,536 | 11,5 kg | 48 % de la correcta |
| 0,30 m | 0,500 | 10,0 kg | 55 % de la correcta |
| 0,35 m | 0,429 | 7,4 kg | 75 % de la correcta |

Con 5,5 kg el modelo se hunde **menos** de lo que corresponde, el término de compactación sale
subestimado y la predicción del rover real queda **baja**. Es el error inverso al de §3 (que era
conservador): este va del lado inseguro. **El Ensayo D definitivo en arena no se corre en este
estado.** Los ensayos 0, A, A', B, C y D0 no dependen de la escala.

| | A. Reimprimir ruedas (**recomendada**) | B. Mantener 150 mm y lastrar |
|---|---|---|
| Qué implica | 104 / 111 / 130 mm con 5,5 kg; 108 / 116 / 136 mm con 6,0 kg | llevar el modelo a 7,4 / 10,0 / 11,5 kg |
| Torque y corriente por rueda | 0,25 a 0,31 N·m; 0,62 a 0,72 A | 0,48 a 0,75 N·m; 1,0 a 1,5 A |
| Térmica del motor (continuo 1,1 a 1,65 A) | al 40–60 % | en la banda límite |
| Servos y estructura | sin cambios | el doble de carga normal: más torque de giro en los servos (empeora V3) |
| Costo | tiempo de impresión | lastre y posible refuerzo |

Margen de velocidad de cada caso (mismo criterio que §2, generalizado al diámetro real: 1 m/s del
rover real llevado al modelo con ω/√λ; torque del informe de Mecánica escalado con λ³):

| Opción | Rover real | Masa | Rueda | T (N·m) | I (A) | rpm pedidas | rpm disponibles | Margen |
|---|---|---|---|---|---|---|---|---|
| Reimprimir | 0,28 m | 5,5 kg | 104 mm | 0,248 | 0,62 | 112,0 | 110,5 | −1,3 % |
| Reimprimir | 0,30 m | 5,5 kg | 111 mm | 0,266 | 0,65 | 104,5 | 109,8 | 5,1 % |
| Reimprimir | 0,35 m | 5,5 kg | 130 mm | 0,310 | 0,72 | 89,6 | 108,1 | 20,7 % |
| Lastrar | 0,28 m | 11,5 kg | 150 mm | 0,748 | 1,46 | 93,2 | 91,4 | −1,9 % |
| Lastrar | 0,30 m | 10,0 kg | 150 mm | 0,652 | 1,30 | 90,0 | 95,1 | 5,6 % |
| Lastrar | 0,35 m | 7,4 kg | 150 mm | 0,479 | 1,01 | 83,4 | 101,7 | 22,0 % |

Si el rover real resulta de 0,28 m, ninguna opción llega a la velocidad escalada (1 a 2 % corto).
Para los ensayos de tracción, que son casi estáticos, no invalida el resultado.

**Recomendación: A.** Se sacrifica esperar el diámetro real y el peso final antes de imprimir; se
evita llevar motor, servos y estructura al límite. Condición para imprimir: diámetro real confirmado
por Mecánica y modelo pesado con todo montado.

---

## 1. El número

$$\lambda = \sqrt{\frac{m_{modelo}}{m_{real}}} = \sqrt{\frac{5{,}5}{40}} = 0{,}371$$

La escala pasa de 0,34 a 0,371, un 9% más grande. Toda la geometría se corre con ella:

| Magnitud | λ = 0,34 (plan) | λ = 0,371 (real) | Δ |
|---|---|---|---|
| Diámetro de rueda | 102 mm | 111 mm | +9% |
| Largo | 272 mm | 297 mm | +9% |
| Ancho | 136 mm | 148 mm | +9% |
| Altura del centro de masa | 118 mm | 129 mm | +9% |
| Altura de obstáculo de ensayo | 34 mm | 37 mm | +9% |
| Factor 1/λ³ (término de peso) | 25,44 | 19,61 | −23% |
| Factor 1/λ² (compactación) | 8,65 | 7,27 | −16% |

## 2. El motor sigue sirviendo, y con más margen

| m (kg) | λ | D rueda (mm) | T requerido (N·m) | RPM requeridas | RPM disponibles | Margen | I por motor (A) |
|---|---|---|---|---|---|---|---|
| 4,6 | 0,339 | 102 | 0,203 | 109,3 | 112,2 | 2,7% | 0,54 |
| 5,5 | 0,371 | 111 | 0,266 | 104,5 | 109,8 | 5,1% | 0,65 |
| 6,0 | 0,387 | 116 | 0,303 | 102,3 | 108,4 | 6,0% | 0,71 |
| 6,5 | 0,403 | 121 | 0,342 | 100,3 | 106,9 | 6,6% | 0,78 |
| 7,0 | 0,418 | 126 | 0,382 | 98,4 | 105,4 | 7,1% | 0,85 |

**El margen mejora al engordar el modelo.** El requisito de velocidad angular cae con la masa a la
potencia −0,25: el modelo es más grande, la rueda es más grande, y hacen falta menos vueltas para
replicar la misma velocidad real. El torque requerido sube, pero desde el 6,5% del torque de bloqueo
hasta el 8,5%: la curva torque-velocidad casi no se entera.

**Verificación térmica:** 0,65 A contra un límite continuo conservador de 1,1 a 1,65 A. Al 40 a 60%.
El techo térmico recién se alcanza cerca de los 8,7 kg.

**Bonus:** el conflicto de empaquetado señalado en la lista de verificación del protocolo (dos
motores de 70 mm enfrentados necesitan 140 mm, y el ancho escalado eran 136 mm) se resuelve solo: a
λ = 0,371 el ancho pasa a 148 mm.

## 3. El problema real es la rueda, no el peso

**λ se define por el diámetro de rueda, no por la masa**, porque la resistencia a la compactación
depende del ancho de contacto y del hundimiento, que son geométricos.

Con 5,5 kg y ruedas de 102 mm (el supuesto original; las ruedas reales son de 150 mm, ver §0)
conviven dos escalas distintas:

- λ geométrico = 102 / 300 = 0,34
- λ másico = raíz de (5,5/40) = 0,371

La masa correcta para ruedas de 102 mm sería 4,62 kg. Hay 0,88 kg de más, o sea **19% de exceso de
presión de contacto**. En arena el modelo se hunde más de lo representativo, el término de
compactación sale sobreestimado, y la predicción del rover real queda sesgada hacia arriba en
aproximadamente ese mismo porcentaje.

Es un error conservador (sobredimensiona el motor), pero es un error, y entra multiplicado en la
sensibilidad dominante del proyecto:

$$\frac{\Delta T}{T} \approx 3\,\frac{\Delta\lambda}{\lambda}$$

**Atención:** λ geométrico usa 300 mm como diámetro del rover real, que es uno de los tres valores en
circulación. El diámetro correcto del modelo según cada valor:

| Diámetro del rover real | Diámetro correcto del modelo (λ = 0,371) |
|---|---|
| 0,28 m | 104 mm |
| 0,30 m | 111 mm |
| 0,35 m | 130 mm |

Son 26 mm entre extremos: no reimprimir antes de que Mecánica confirme. Ver [00-contexto/03-conflictos-abiertos.md](../00-contexto/03-conflictos-abiertos.md).

## 4. Las tres salidas

| Opción | Qué implica | Recomendación |
|---|---|---|
| **A. Ruedas a 111 mm** | reimprimir cuatro ruedas, recalcular λ = 0,371, todo cierra | **adoptada**, es la más barata en tiempo |
| B. Bajar a 4,6 kg | sacar 0,9 kg de estructura, batería o electrónica ya montada | difícil, no vale la pena |
| C. Aceptar el desfasaje y corregir a mano | usar el cociente exacto en lugar de 1/λ³ para el término de peso | funciona en piso duro, no cierra en arena |

Aclaración sobre la opción C: el término de peso sí se puede corregir analíticamente, porque la
fuerza es proporcional a masa por radio y ambos se conocen. Pero el término de compactación depende
del ancho de contacto y del hundimiento con un exponente del modelo de Bekker, y ahí no hay
corrección exacta sin caracterizar la arena. Como ese es justamente el término que domina a escala
chica, se descarta.

## 5. Sobre el rango [1, 5] kg del informe de mecánica

Sí, se salió del rango. No importa.

Ese rango era un criterio de constructibilidad de mecánica, no un límite físico: "ni tan liviano que
sea poco manejable, ni tan pesado que encarezca el lastre". El criterio vinculante de verdad está en
la misma sección del informe: **que exista un motorreductor de catálogo que cumpla torque y velocidad
simultáneamente a esa masa**. A 5,5 kg el CQRobot cumple los dos, con más margen que a 4,6 kg.

Lo que sí cambia es que **se acabó el lastre.** El plan original era estructura liviana más lastre
para llegar a 4,6 kg, y el lastre era la variable de ajuste: permitía corregir λ después de construir
y ubicar masa para fijar la altura del centro de masa. Esa libertad ya no existe: no se puede sacar
peso, solo agregar. El diámetro de rueda queda como única variable de ajuste, lo que refuerza la
opción A.

## 6. Altura del centro de masa

El objetivo pasa a **129 mm**. Si la batería quedó baja en el chasis (lo normal por estabilidad),
probablemente esté por debajo de ese valor. Si está por debajo, el modelo vuelca a un ángulo mayor
que el rover real, o sea que el ensayo es optimista en estabilidad. No invalida los ensayos de
tracción, pero sí cualquier conclusión sobre vuelco.

## 7. Riesgos de escala

- **Si el peso sigue creciendo** (cableado, conectores, guardapolvos de arena), λ se mueve otra vez.
  Conviene congelar el peso antes de imprimir las ruedas definitivas, o directamente pesar el modelo
  completo con todo montado.
- **El margen de velocidad del 5% sigue siendo estructuralmente chico.** Una caída del 8% de tensión
  de batería se lo come entero. ~~La alimentación por convertidor reductor regulado a 12,00 V no es
  opcional.~~ **Corrección (27-sep):** el modelo usa batería de plomo de 12 V directo al bus, sin
  convertidor. Lo que hace comparables dos corridas pasa a ser el lazo cerrado de velocidad con margen
  de ciclo de trabajo, el registro de tensión y D en cada muestra, arrancar con la batería en reposo
  ≥ 12,6 V y descartar corridas con D saturado. El D0 verifica que la velocidad no mueve el umbral.
  Ver [50-ensayos/plan-de-ensayos.md](50-ensayos/plan-de-ensayos.md).

Los riesgos de medición están en [50-ensayos/instrumentacion.md](50-ensayos/instrumentacion.md).

## 8. Motor y configuración del modelo

**Motor:** CQRobot CQR37D12V64EN-I ×4. 37D, 12 V, 90:1, 120 rpm sin carga, τ_stall 3,138 N·m,
I_stall 5,5 A, I₀ 0,2 A, encoder 64 CPR en el eje del motor → 5760 CPR en el eje de salida, ~22 USD.

**Configuración:** swerve, con un servo de dirección por rueda. Ya no es skid-steer. Con eso el
modelo sí valida la cinemática swerve, que era su laguna principal.

## 9. Qué valida el modelo y qué no

| Valida | No valida |
|---|---|
| Tracción y torque real en dos superficies | Cualquier magnitud eléctrica o térmica |
| Cinemática swerve | Rendimiento del tren motriz real |
| Control de velocidad por rueda | Constante térmica del motor grande |
| Firmware y telemetría | Corriente de arranque, ondulación, EMI |
| μ real por ángulo de deslizamiento | Cargas de rodamiento del cubo full-scale |

Regla práctica: **si la magnitud tiene unidades eléctricas o térmicas, el modelo no la dice.** El
detalle de por qué cada magnitud eléctrica o térmica no escala está en
[10-rover-final/20-potencia/presupuesto-corriente.md](../10-rover-final/20-potencia/presupuesto-corriente.md) §6.

---

## Anexo. Constantes recalculadas

| Símbolo | Valor rev. 1.0 | Valor vigente | Origen |
|---|---|---|---|
| λ | 0,34 | 0,371 | masa real del modelo, 5,5 kg |
| 1 / λ² | 8,65 | 7,27 | factor del término de compactación |
| 1 / λ³ | 25,44 | 19,61 | factor del término de peso |
| Masa del modelo | 4,6 kg (objetivo) | 5,5 kg (real) | pesado con electrónica y batería |
| Diámetro de rueda del modelo | 102 mm | 111 mm | derivado de λ |
| Altura del CM del modelo | 118 mm | 129 mm | derivado de λ |
| Torque de trabajo por rueda | 0,203 N·m | 0,266 N·m | criterio del informe a 5,5 kg |
| Corriente de trabajo por motor | 0,54 A | 0,65 A | derivada de K |

El techo de tracción del rover real y la potencia continua de tracción no dependen de λ: se calculan
en [10-rover-final/20-potencia/presupuesto-corriente.md](../10-rover-final/20-potencia/presupuesto-corriente.md).

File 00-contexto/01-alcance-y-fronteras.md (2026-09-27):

---
titulo: Alcance y fronteras del subsistema de Electrónica y Potencia
estado: vigente
fecha: 2026-09-16
fuente: 00-contexto-maestro.md §2, con la tabla de interfaces armada desde §4 y §5
---

# Alcance y fronteras

Qué entra en este subsistema, qué no, y por dónde pasa exactamente la costura con Mecánica. La
versión corta vive en el [contexto maestro](00-contexto-maestro.md) §2; acá está el detalle y la
tabla de interfaces.

---

## 1. Dentro del alcance

Batería y BMS, distribución de potencia, control de motores, protecciones, sensado, firmware,
telemetría.

## 2. Fuera del alcance

Diseño estructural, cinemático y de transmisión (subequipo de Mecánica). Entra solo como interfaz.

**Explícitamente fuera:** la derivación del factor de escala λ por parte de Mecánica. λ entra como
dato de entrada. Lo que sí es de este subsistema es la ecuación de extrapolación de torque y su
sensibilidad.

La distinción no es burocrática: es la que determina qué se discute y qué se acepta. Un número que
viene de Mecánica no se recalcula acá, se usa o se cuestiona con una medición. Un número que sale de
acá no se delega.

---

## 3. Interfaces con Mecánica

Cada fila es un dato que cruza la frontera. La columna de estado dice si el dato está cerrado o si
hoy bloquea algo de este lado.

| Dato | Dirección | Valor o dónde vive | Estado | Qué depende de él |
|---|---|---|---|---|
| Masa del rover real | Mecánica → Electrónica | 40 kg | cerrado | λ, techo de tracción, presupuesto de corriente |
| Chasis | Mecánica → Electrónica | 0,8 × 0,4 m | cerrado | Ubicación de PDB y batería |
| Configuración de tracción | Mecánica → Electrónica | Swerve de 4 ruedas. Por rueda: NEMA 23 para la dirección, motor de tracción a definir | cerrado | Cantidad de drivers, arquitectura de control |
| Diámetro de rueda del rover real | Mecánica → Electrónica | tres valores en circulación, ver [03-conflictos-abiertos.md](03-conflictos-abiertos.md) | **en conflicto** | Torque y velocidad requeridos, λ, diámetro de rueda del modelo |
| μ del terreno | Mecánica → Electrónica | ver [03-conflictos-abiertos.md](03-conflictos-abiertos.md) | **en conflicto**, se mide de este lado | Techo de tracción, elección del motor |
| Pendiente máxima | Mecánica → Electrónica | ver [03-conflictos-abiertos.md](03-conflictos-abiertos.md) | **en conflicto**: falta saber si es sostenida o puntual | Requisito de torque continuo |
| Requisitos de torque y velocidad por rueda | Mecánica → Electrónica | [requisitos-motor.md](../10-rover-final/10-locomocion/requisitos-motor.md) | vigente, inconsistente con el techo de tracción | Selección de motor y driver |
| Factor de escala λ | Mecánica → Electrónica | [10-metodologia-similitud.md](../20-modelo-escala/10-metodologia-similitud.md), derivado de la masa real del modelo | vigente | Toda la extrapolación del modelo |
| Ecuación de extrapolación de torque y su sensibilidad | Electrónica | [10-metodologia-similitud.md](../20-modelo-escala/10-metodologia-similitud.md) | vigente | Validez de los ensayos |
| μ medido por ángulo de deslizamiento | Electrónica → Mecánica | pendiente de ensayo | pendiente | Cierra el conflicto 2 con un dato, no con una pregunta |
| Presupuesto de corriente y batería | Electrónica | [presupuesto-corriente.md](../10-rover-final/20-potencia/presupuesto-corriente.md): tracción calculada | parcial: falta brazo, cómputo, comunicaciones y ciencia | Batería y PDB del rover final |

Los tres conflictos abiertos de la tabla se tratan en
[03-conflictos-abiertos.md](03-conflictos-abiertos.md), que incluye la consulta consolidada a
Mecánica.

---

## 4. Frontera con el modelo a escala

El modelo a escala es un instrumento de este subsistema, no una entrega de Mecánica. Su única razón
de ser es cerrar la especificación de motores sin comprar motores de tamaño real a ciegas.

Lo que el modelo aporta y lo que no está en
[20-modelo-escala/10-metodologia-similitud.md](../20-modelo-escala/10-metodologia-similitud.md).
Regla práctica: si la magnitud tiene unidades eléctricas o térmicas, el modelo no la dice.

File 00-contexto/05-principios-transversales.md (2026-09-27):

---
titulo: Principios transversales
estado: vigente
fecha: 2026-09-16
fuente: 00-contexto-maestro.md §8
---

# Principios transversales

Reglas ganadas en el proyecto que aplican más allá del caso que las originó. El [contexto maestro](00-contexto-maestro.md) §2
solo los enlaza; acá está el enunciado completo y el
lugar donde cada una se puso a prueba.

---

## Los trece

1. **La tracción es la restricción vinculante, no el par del motor.** Si el modelo predice más torque
   que el techo de tracción, no significa que hagan falta motores más grandes: significa que el rover
   patina antes de poder aplicarlo.
2. **El error en λ es cúbico:** ΔT/T ≈ 3·Δλ/λ.
3. **El pico de corriente de la PDB no ocurre trepando el obstáculo.** Trepar pide mucho torque a
   velocidad baja, o sea ciclo de trabajo bajo, o sea poca corriente de bus. El peor caso de bus es
   rueda trabada con el lazo pidiendo velocidad alta.
4. **I_bus ≈ D · I_motor, pero el cable driver-motor ve la corriente plena.** Dos dimensionamientos
   distintos sobre la misma rama.
5. **La corriente como proxy de torque exige continua sin modulación** en el banco de calibración.
6. **Los pull internos del ESP32 no sirven para nada crítico:** dispersión de 30–80 kΩ, ausentes
   durante los 100–300 ms del arranque, inexistentes en IO34–IO39.
7. **Los capacitores de bulk tienen que estar en la carga**, no en el PDB, si hay cable en el medio.
   La inductancia del cable (~1 µH/m) domina a frecuencia de conmutación.
8. **El standoff del TVS se elige contra la tensión máxima real de bus**, incluyendo carga.
9. **Los contactos de relé se sueldan por inrush.** El síntoma es que la seta deja de cortar y nadie
   se entera hasta que hace falta.
10. **El fusible protege el cableado, no la carga.** Y el conector también tiene un límite: la cadena
    conector-fusible-cable tiene que ser coherente.
11. **El dato que define el driver es la corriente de bloqueo a la tensión de bus**, no la nominal.
12. **Un pull-down del lado del GPIO no protege contra un cable desconectado.** Va del lado del
    driver.
13. **La repetibilidad del terreno domina sobre la precisión del instrumento.** El estado de
    compactación de la arena varía más entre corridas que cualquier error de medición.

---

## De dónde salió cada uno

| # | Caso que lo originó | Dónde se discute |
|---|---|---|
| 1 | Techo de tracción contra el torque pedido por Mecánica | [presupuesto-corriente.md](../10-rover-final/20-potencia/presupuesto-corriente.md) |
| 2 | Desfasaje entre λ geométrico y λ másico del modelo | [10-metodologia-similitud.md](../20-modelo-escala/10-metodologia-similitud.md) |
| 3, 4 | Presupuesto de corriente de la PDB del rover final | [presupuesto-corriente.md](../10-rover-final/20-potencia/presupuesto-corriente.md) |
| 5 | Ensayo A de calibración de K, en banco y sin modulación | [instrumentacion.md](../20-modelo-escala/50-ensayos/instrumentacion.md) |
| 6, 12 | Pines de strapping, NLAS4157 y arranque del ESP32 | [mapa-gpio.md](../20-modelo-escala/40-firmware/mapa-gpio.md) y [drivers-bts7960.md](../20-modelo-escala/20-electronica/drivers-bts7960.md) |
| 7 | Desacople local de los BTS7960 a 60–100 cm del PDB | [drivers-bts7960.md](../20-modelo-escala/20-electronica/drivers-bts7960.md) |
| 8, 9 | TVS SM6T15A (V5) e inrush del contacto de K1 (V7) | [protecciones-desacople.md](../20-modelo-escala/20-electronica/protecciones-desacople.md) |
| 10 | Márgenes de J1 y J4..J7 contra el valor de los fusibles (V4) | [mapa-conectores.md](../20-modelo-escala/30-pcb/mapa-conectores.md) |
| 11 | Criterio de búsqueda del motor de reemplazo del 42RBL04A | [candidatos-motores.md](../10-rover-final/10-locomocion/candidatos-motores.md) |
| 13 | Ensayo de arena y repetibilidad del terreno | [plan-de-ensayos.md](../20-modelo-escala/50-ensayos/plan-de-ensayos.md) |

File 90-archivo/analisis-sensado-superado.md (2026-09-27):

---
titulo: Análisis superado — el sensor mediría el total de la PDB
estado: superado
fecha: 2026-09-16
fuente: metodologia-modelo-escala-y-presupuesto-pdb.md §3.1 y §3.2
---

# Análisis superado: la limitación del sensado que no era

> **Qué se creyó, qué se verificó y cuándo.**
>
> **Se creyó** (hasta el 15-sep-2026) que el TMCS1126 de la placa del modelo medía el **consumo total
> de la PDB** —tracción más servos más lógica— y que por eso el Ensayo D quedaba invalidado: los
> picos de los servos de dirección, de hasta 10 A, son del mismo orden que la señal de tracción que
> se quiere medir. De esa premisa salieron tres correcciones: un puente sobre la placa, un instrumento
> externo obligatorio, y el Ensayo A fuera de la PDB.
>
> **Se verificó** el 16-sep-2026, contra el esquemático de KiCad, que la premisa es **incorrecta**. El
> sensor está en la rama conmutada, entre el contacto NO del relé y el riel de +12 V de los cuatro
> drivers. El LM2596 —y con él el ESP32 y los servos— cuelga del nodo A, aguas arriba del relé, y no
> atraviesa el sensor. Lo confirma una consecuencia arquitectónica ya documentada: al apretar la seta
> muere el bus de los drivers pero los servos y el ESP32 siguen alimentados.
>
> **Consecuencia:** el sensor mide **solo la rama de tracción**, el Ensayo D es válido con el sensor
> de a bordo, el puente sobre la placa es innecesario y el instrumento externo pasa a mejora
> opcional. El único término parásito es el VCC lógico de los cuatro BTS7960 (10 a 30 mA), constante
> y restable como línea de base.
>
> **Vigente hoy:**
> [20-modelo-escala/20-electronica/sensado-corriente.md](../20-modelo-escala/20-electronica/sensado-corriente.md)
> e [20-modelo-escala/50-ensayos/instrumentacion.md](../20-modelo-escala/50-ensayos/instrumentacion.md).
>
> Se conserva el texto original porque sin esta nota el mismo razonamiento vuelve a aparecer desde
> cero dentro de tres meses.

---

## Texto original (superado)

### 3.1 El problema

El TMCS1126 **no está midiendo la rama de tracción: está midiendo el consumo total de la PDB.** Eso incluye tracción, servos de dirección, lógica y cualquier otra carga aguas abajo del relé.

Consecuencias por ensayo:

| Ensayo | ¿Afecta? | Por qué |
|---|---|---|
| A (calibración) | no, si se hace en banco | el motor se alimenta directo desde la fuente, fuera de la PDB |
| B (fcem) | no | ídem |
| C (encoder) | no | no usa corriente |
| **D (tracción)** | **sí, lo invalida** | los servos consumen durante el ensayo y su consumo no es constante |

El punto crítico es el Ensayo D. Restar una línea de base funciona para un consumo **constante** (lógica), pero los servos de dirección del swerve mantienen torque durante el ascenso de la rampa y su corriente varía de forma impredecible, con picos de varios amperes. Ese consumo entra sumado a la corriente de tracción y no hay forma de separarlo a posteriori.

Peor: los picos de servo son del mismo orden que la señal que se quiere medir (2,6 A de tracción contra picos de servo de hasta 10 A por la especificación de la rama), así que no es un error pequeño sino una contaminación total de la medición.

### 3.2 Opciones ordenadas

La opción A de esta tabla (Ensayo A fuera de la PDB) **no está acá**: sigue vigente por un motivo
propio, independiente de esta premisa, y se movió a
[20-modelo-escala/50-ensayos/plan-de-ensayos.md](../20-modelo-escala/50-ensayos/plan-de-ensayos.md).

| Opción | Qué implica | Costo | Veredicto |
|---|---|---|---|
| **B. Puente sobre la placa actual** | cortar la pista de entrada a la rama de tracción y reinsertar el sensor ahí; si hay portafusible o conector en esa rama, se hace sin cortar nada | 0 a 2 | **la corrección definitiva** para la placa del modelo |
| **C. Instrumento externo independiente** | módulo aparte con sensor Hall + ADS1115 + microcontrolador propio, intercalado en el cable de la rama de tracción con conectores XT | 15 a 20 | **la mejor opción para los ensayos** |
| D. Sensor por motor | cuatro sensores, cuatro canales | 60 | no se justifica (ver 2.1) |

**Plan adoptado: A para el Ensayo A, C para el Ensayo D, B como corrección definitiva de la placa.**

Ese plan adoptado ya no rige: la opción B es innecesaria y la C quedó degradada a opcional.

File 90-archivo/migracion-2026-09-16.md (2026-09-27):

---
titulo: Plan de migración — fragmentar los documentos fuente en el árbol del repo
fecha: 2026-09-16
destinatario: Claude Code
estado: listo para ejecutar
---

# Plan de migración

Instrucciones para construir el repositorio. Ejecutar en orden. No inventar contenido: todo sale de
los cuatro documentos fuente listados abajo.

## Documentos fuente

| Archivo | Rol |
|---|---|
| `00-contexto-maestro.md` | Documento raíz. Va casi entero a `00-contexto/`. |
| `pcb-modelo-escala.md` | Detalle de la placa. **Ya viene fragmentado**: cada `##` es un archivo destino. |
| `metodologia-modelo-escala-y-presupuesto-pdb.md` | Escala, instrumentación y presupuesto de corriente. Se reparte entre tres carpetas. |
| `requisitos-motor-rover-real.md` | Requisitos del motor grande. Va casi entero a un archivo. |

## Reglas de fragmentación

1. **No reescribir.** Mover el texto tal cual, salvo lo que estas instrucciones indiquen
   explícitamente. Es contenido ya revisado.
2. **Frontmatter en cada archivo:** `titulo`, `estado`, `fecha`, `fuente` (de qué documento salió).
3. **Los enlaces cruzados son markdown relativo**, nunca wikilinks.
4. **Si una sección queda por debajo de 40 líneas**, fusionarla con la contigua en lugar de crear un
   archivo anémico. Los casos candidatos están marcados abajo.
5. **No duplicar tablas entre archivos.** Si dos archivos necesitan la misma tabla, uno la tiene y el
   otro enlaza.
6. **Al final, generar `README.md`** con el árbol y una línea de descripción por archivo.

---

## Árbol a crear

```
rover-erc/
├── README.md
├── CLAUDE.md
├── 00-contexto/
│   ├── 00-contexto-maestro.md
│   ├── 01-alcance-y-fronteras.md
│   ├── 02-filosofia-de-diseno.md
│   ├── 03-conflictos-abiertos.md
│   ├── 04-decisiones-descartadas.md
│   └── 05-principios-transversales.md
├── 10-rover-final/
│   ├── 10-locomocion/
│   │   ├── requisitos-motor.md
│   │   └── candidatos-motores.md
│   └── 20-potencia/
│       ├── presupuesto-corriente.md
│       └── cableado-y-protecciones.md
├── 20-modelo-escala/
│   ├── 00-estado-actual.md
│   ├── 10-metodologia-similitud.md
│   ├── 20-electronica/
│   │   ├── arquitectura-electrica.md
│   │   ├── encoders-pcnt.md
│   │   ├── drivers-bts7960.md
│   │   ├── direccion-swerve-servos.md
│   │   ├── sensado-corriente.md
│   │   └── protecciones-desacople.md
│   ├── 30-pcb/
│   │   ├── especificacion.md
│   │   ├── decisiones-layout.md
│   │   ├── mapa-conectores.md
│   │   ├── bom.md
│   │   └── pendientes-de-verificacion.md
│   ├── 40-firmware/
│   │   └── mapa-gpio.md
│   └── 50-ensayos/
│       ├── instrumentacion.md
│       └── plan-de-ensayos.md
├── 30-componentes/
├── 40-proveedores-costos/
└── 90-archivo/
```

---

## Mapeo detallado

### Desde `00-contexto-maestro.md`

| Sección origen | Destino |
|---|---|
| Completo | `00-contexto/00-contexto-maestro.md` (queda como raíz, sin recortar) |
| §2 Alcance | también `00-contexto/01-alcance-y-fronteras.md`, ampliado con la tabla de interfaces con Mecánica |
| §3 Reglas de diseño | `00-contexto/02-filosofia-de-diseno.md` |
| §4 Conflictos abiertos | `00-contexto/03-conflictos-abiertos.md` |
| §8 Principios transversales | `00-contexto/05-principios-transversales.md` |

El maestro conserva versiones resumidas de §2, §3, §4 y §8 con enlace al archivo detallado. Es el
único caso donde se permite duplicación parcial, porque el maestro tiene que poder leerse solo.
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

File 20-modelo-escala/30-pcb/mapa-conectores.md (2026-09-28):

---
titulo: Mapa de conectores de la PCB del modelo
estado: vigente
fecha: 2026-09-27
fuente: pcb-modelo-escala.md, sección mapa-conectores
---

# Mapa de conectores

Tabla completa de los 19 conectores de la placa, con huella, pinout, corriente nominal y corriente
esperada. Las columnas de pin nombran GPIO del ESP32 donde corresponde; la asignación completa y
su justificación están en [40-firmware/mapa-gpio.md](../40-firmware/mapa-gpio.md), que es la fuente
única de verdad del pinout.

### Tabla completa
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

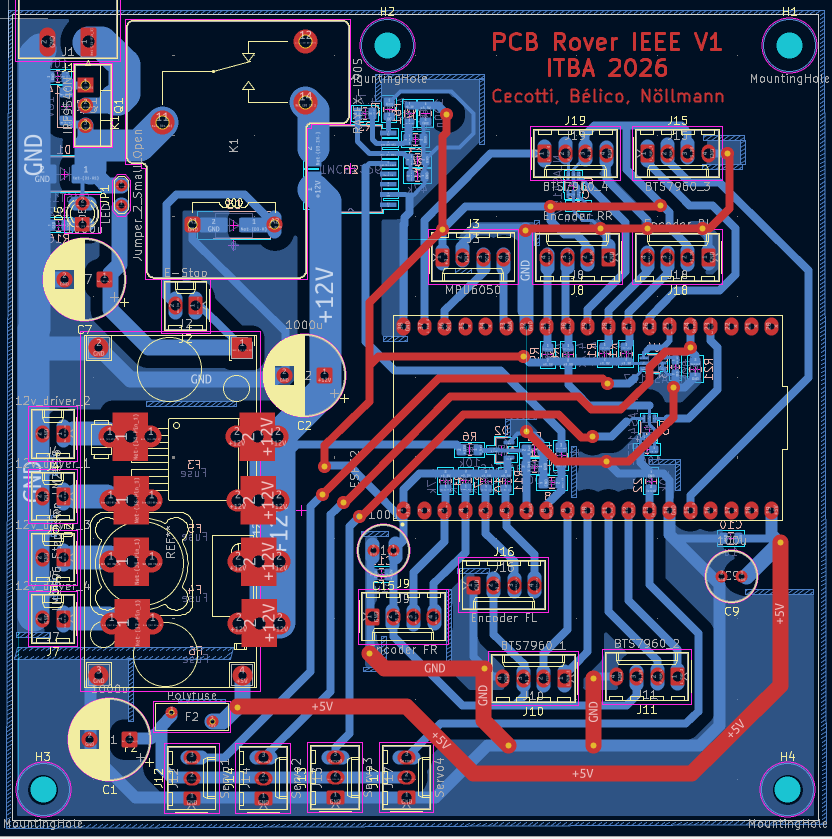
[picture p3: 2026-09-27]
audiovisual-presentacion/PCB Routeada.png

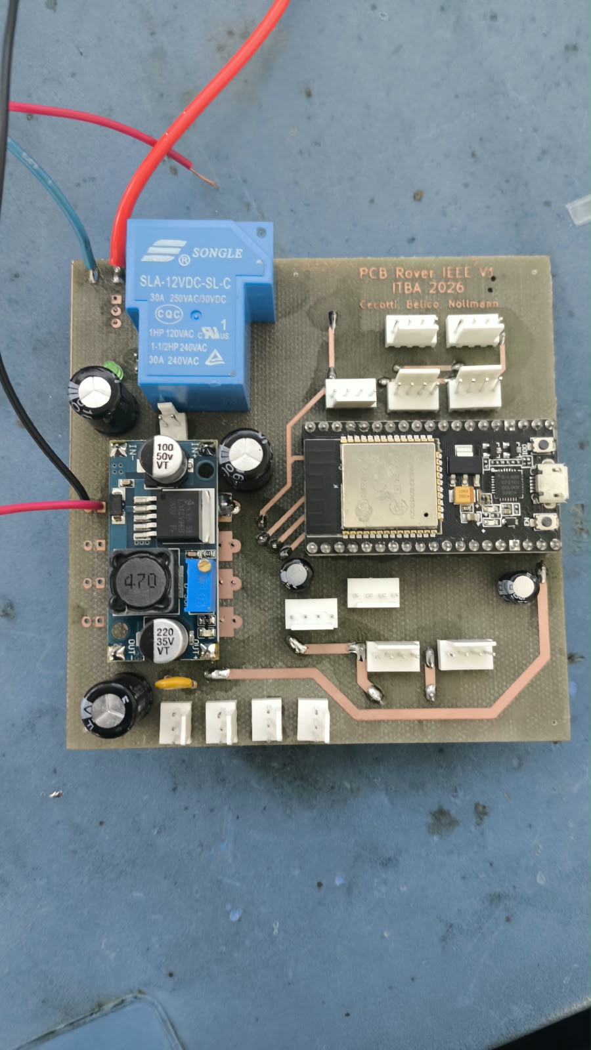
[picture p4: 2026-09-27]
audiovisual-presentacion/Foto pcb1.jpeg

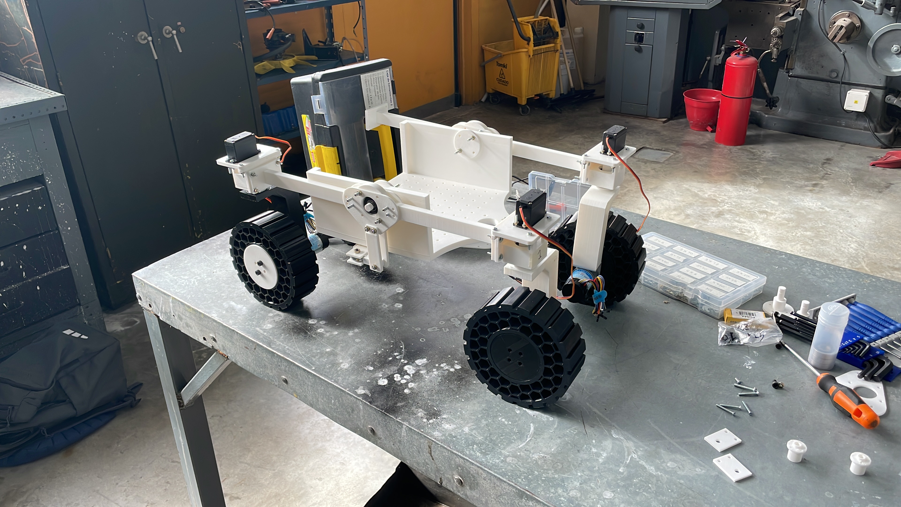
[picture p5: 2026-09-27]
audiovisual-presentacion/Foto chasis.JPG

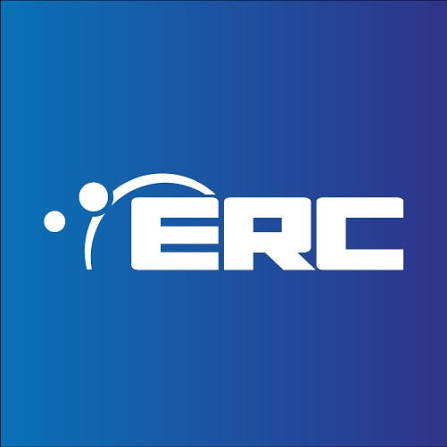
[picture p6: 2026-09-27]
audiovisual-presentacion/images.jpg

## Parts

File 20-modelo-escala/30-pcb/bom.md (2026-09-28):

---
titulo: BOM de la PCB del modelo
estado: vigente
fecha: 2026-09-27
fuente: pcb-modelo-escala.md, sección bom
---

# BOM

### Lista completa por referencia

| Ref | Valor | Huella | Función |
|---|---|---|---|
| ESP1 | ESP32-DEVKITC (38 pines) | zócalo | control, PCNT, PWM, ADC, I2C |
| U1 | NLAS4157 | SOT-363 / SC-70-6 | conmutador de R_PWM_4, aísla el strapping IO5 |
| U2 | LM2596 (módulo step-down) | módulo | 12 V a 5 V o 7,2 V |
| U3 | **TMCS1126B4** | SOIC-10 DVG | sensor de corriente total de tracción, 100 mV/A |
| U4 | NLAS4157 | SOT-363 | conmutador de Servo1, aísla IO0 |
| U5 | NLAS4157 | SOT-363 | conmutador de Servo3, aísla IO15 |
| Q1 | IRF9540N | TO-220 vertical | polaridad inversa. **Puenteado desde el 27-sep, no se usa** |
| K1 | RAYEX-L90S (relé automotriz 12 V) | THT SPDT | corte de la rama de tracción |
| D1 | SM6T15A | SMB | TVS en el nodo A (ver V5) |
| D2 | BAT54S | SOT-23 | clamp doble Schottky en la entrada de ADC de batería |
| D3 | diodo estándar | SMA | antirretorno de la bobina del relé |
| D4 | zener 16 V | MiniMELF | protección de compuerta de Q1 |
| D5 | LED | 3 mm THT | indicación de bus energizado (~4,5 mA) |
| F2 | PTC rearmable | huella de disco 9 mm (corregir) | protección del riel de servos. Valor sin definir |
| F3, F4, F5, F6 | fusible 5x20 mm a clip | FuseClip 5x20 | uno por driver. Valor sin definir |
| FB1 | ferrita (1 k a 100 MHz) | 0805 | filtro de alimentación del sensor |
| C1 | 1000 uF | radial D10, P5 | reserva del riel de servos |
| C2 | 1000 uF | radial D10, P5 | reserva del bus +12 V conmutado |
| C7 | 1000 uF | radial D10, P5 | entrada del LM2596 |
| C9, C15 | 100 uF | radial D6,3 | salida de 5 V y riel de 3,3 V |
| C10, C11 | 1 uF | 0805 | acompañan a los de 100 uF |
| C5 | 1 uF | 0805 | estabilidad de VOC (sugerido 10 uF) |
| C3, C4 | 100 nF | 0805 | filtro en pi de la alimentación del sensor |
| C6 | 100 nF | 0805 | filtro del divisor de batería |
| C8 | 100 nF | 0805 | filtro de la salida del sensor |
| C12, C13, C14 | 100 nF | 0603 | desacople de los NLAS4157 |
| R1, R7, R8, R9, R10, R11, R12, R13 | 4,7 k | 0805 | pull-ups de los 8 canales de encoder |
| R2 | 4,7 k | 0805 | pin OC del sensor a masa (ver V9) |
| R3 | 4,7 k | 0805 | divisor de VOC, rama superior (ver V9) |
| R4 | 47 k | 0805 | divisor de VOC, rama inferior (ver V9) |
| R5 | 2,2 k | 0805 | divisor de batería, rama inferior |
| R6 | 10 k | 0805 | divisor de batería, rama superior |
| R14 | 10 k | 0805 | pull-down de compuerta de Q1 |
| R15 | 1 k | 0805 | serie del filtro de salida del sensor |
| R16 | 2,2 k | 0805 | limitadora del LED |
| R21, R22 | 10 k | 0805 | pull-down de IO2 e IO12 (strapping) |
| J1..J19 | ver [mapa-conectores.md](mapa-conectores.md) | — | — |
| JP1 | puente de 2 pads | TestPoint 2,54 mm | habilita la rama permanente |
| H1..H4 | agujero M3 | MountingHole 3,2 mm | fijación al chasis |

Referencias no usadas en el esquemático: R17 a R20 (saltadas en la numeración).

### Ítems sin valor definido

| Ref | Falta | Propuesta |
|---|---|---|
| F3..F6 | valor | 7,5 a 8 A retardado (T), 5x20 mm, una vez resuelto V4 |
| F2 | valor | depende de si se separa el riel de servos. Con riel compartido: 3 A de mantenimiento |
| Fusible general | valor y ubicación | 15 A si J1 sigue siendo Phoenix; 20-25 A si se pasa a XT60 |
| D3 | número de parte | cualquier rectificador de 1 A / 100 V (1N4007, S1M) |
| D4 | número de parte | zener 16 V / 500 mW |

### Compras adicionales que no están en el BOM de la placa

Parte del diseño aunque se monten fuera de la PCB:

- 8 x capacitor 470 uF / 25 V / 105 °C de bajo ESR (2 por driver BTS7960).
- 4 x capacitor 100 nF cerámico (uno por driver).
- 4 x resistencia 10 k para pull-down de PWM, montadas del lado del driver.
- 8 x resistencia 220 Ω de terminación serie (opcional, en los conectores de señal).
- 1 x portafusible aéreo + fusible general.
- 1 x seta de emergencia NC de 40 mm con retención.
- Punteras tubulares para todos los cables de potencia multifilares.

### Agregados del 27-sep-2026

| Ítem | Tipo de cambio | Estado |
|---|---|---|
| Resistencia de pull-up en L_PWM_4 (V1) | componente agregado, sin cortes | soldada; **valor a asentar** |
| Puente sobre Q1 | puente | hecho |
| Módulo ADS1115 (16 bits, I2C, 0x48) | fuera de placa, en el bus I2C de J3 | comprado |
| Módulo ACS712-30A | fuera de placa, en la pata de motor de una rueda delantera | disponible |
| Regulador lineal de 5 V para el ACS712 (78L05 o AMS1117-5.0) con sus capacitores | fuera de placa | a comprar (~1 USD) |
| Mazo en Y para J3 (Molex KK-254, 4 vías) | mazo | a armar |
| Cable trenzado con masa desde Vout_CS (pad de C8 o pin IO33) a AIN0 | agregado de cable, sin cortes | a hacer |
| 2 × 10 k serie en AIN1 y AIN3; divisor 1:2 para AIN2 | fuera de placa | a comprar |

---

Valores de fusible y pendientes de especificación en [especificacion.md](especificacion.md); conectores en [mapa-conectores.md](mapa-conectores.md).

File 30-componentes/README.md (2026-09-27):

---
titulo: Componentes — ficha por parte
estado: pendiente
fecha: 2026-09-16
fuente: migracion.md (carpeta creada vacia)
---

# 30-componentes

Ficha por componente y enlaces a hojas de datos. Se llena a medida que se cierra cada selección.

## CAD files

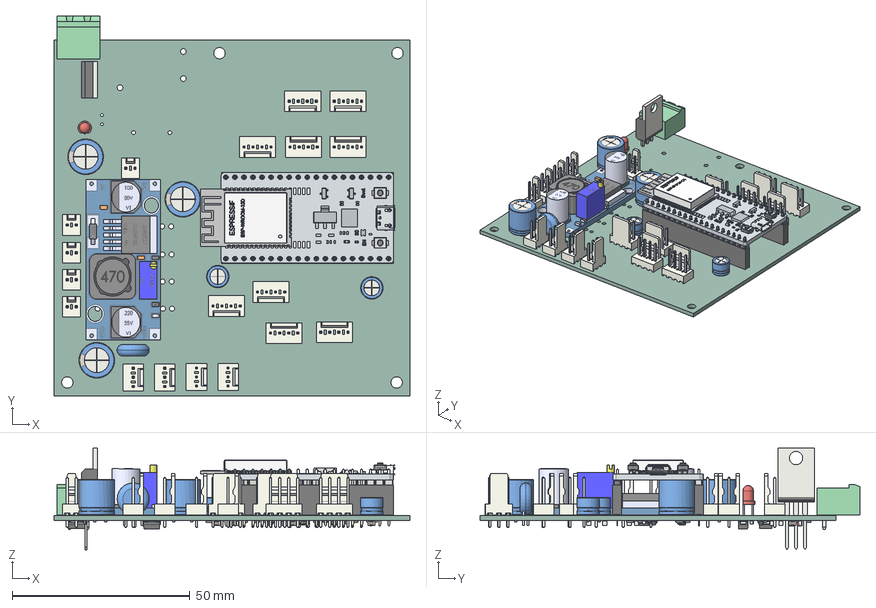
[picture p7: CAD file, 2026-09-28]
pcb_V1/PCB modelo.step
100.0 x 106.6 x 28.5 mm
Molex_KK-254_AE-6410-04A_1x04_P2.54mm_Vertical x 9
Molex_KK-254_AE-6410-02A_1x02_P2.54mm_Vertical x 5
CP_Radial_D10.0mm_P5.00mm x 3
C_Radial_D6.3mm_H5.0mm_P2.50mm x 2
Molex_KK-254_AE-6410-03A_1x03_P2.54mm_Vertical x 4
PCB_mince
Text_ESP32
Text_ESP033
Text_ESP034
Text_ESP035
Text_ESP036
Text_ESP037
Text_ESP038
Text_ESP039
Text_ESP040
Text_ESP041
Text_ESP042
Text_ESP043
Text_ESP044
Text_Espressif
Text_Espressif001
Text_Espressif002
Text_Espressif003
Text_Espressif004
Text_Espressif005
Text_Espressif006
Text_Espressif007
Text_Espressif008
pin_001
pin_002
pin_003
pin_004
pin_005
pin_006
pin_007
pin_008
pin_009
pin_010
pin_011
pin_012
pin_013
pin_014
pin_015
pin_016
pin_017
pin_018
pin_019
pin_020
pin_021
pin_022
pin_023
pin_024
pin_026
pin_027
pin_028
pin_029
pin_030
pin_031
pin_032
pin_033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

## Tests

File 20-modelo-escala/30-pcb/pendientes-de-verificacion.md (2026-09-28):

---
titulo: Pendientes de verificación de la PCB (V1 a V12)
estado: vigente
fecha: 2026-09-27
fuente: pcb-modelo-escala.md, sección pendientes-de-verificacion
---

# Pendientes de verificación (V1 a V12)

Puntos surgidos del análisis del esquemático que **quedan por confirmar en el banco**. No son fallas
comprobadas: varios pueden descartarse con una medición de dos minutos, y algunos ya podrían estar
descartados por las pruebas hechas.

**Cómo se cierra un punto:** se hace la medición de la columna del medio, se actualiza la fila con el
resultado y se lo mueve a resuelto. Un punto sin medición no se cierra por argumento.

Por consecuencia, los que conviene atacar primero son **V1** (si el análisis es correcto, el motor 4
gira solo hasta que el firmware toma el control) y **V3** (cuatro servos trabados pueden resetear el
ESP32 por brownout). Estado al 27-sep: V1 tiene una mitigación aplicada que falta verificar, V3 quedó
en pausa, y V2 dejó de aplicar.

| # | Qué revisar | Cómo se confirma o descarta | Sección |
|---|---|---|---|
| V1 | Nivel de R_PWM_4 durante el arranque del ESP32 (U1 con B1 a 3,3 V). **Mitigado el 27-sep** con un pull-up en L_PWM_4: las dos entradas arrancan en alto y el motor queda frenado. **Falta verificarlo** | osciloscopio disparado en EN, mirando R_PWM_4 y L_PWM_4, con el driver 4 sin potencia; confirmar que L_PWM_4 supera el umbral alto. Después, con el motor conectado, confirmar que no se mueve al encender | [drivers-bts7960](../20-electronica/drivers-bts7960.md) |
| V3 | Margen del riel de servos con el LM2596 compartido con el ESP32. **En pausa (27-sep):** se observa durante los ensayos; por ahora se depende del corte del PTC y de rampas por firmware para bajar los picos | el firmware de ensayo registra la causa de cada reinicio del ESP32; si aparecen reinicios por brownout: trabar los 4 servos y mirar el riel y 3V3 con osciloscopio; shunt de 0,1 Ω en el riel de servos, arranque simultáneo contra escalonado | [direccion-swerve-servos](../20-electronica/direccion-swerve-servos.md) |
| V4 | Márgenes de J1 (12 A nominal) y J4..J7 (3-4 A nominal) | tocar/medir temperatura de los conectores tras un minuto con una rueda trabada | [mapa-conectores](mapa-conectores.md) |
| V5 | Fuga del TVS SM6T15A con la batería recién cargada (13,8-14,4 V) | medir corriente o temperatura de D1 con el rover encendido | [protecciones-desacople](../20-electronica/protecciones-desacople.md) |
| V6 | Pico en el riel conmutado al abrir la seta a plena marcha | osciloscopio en el bus +12 V conmutado durante el corte | [protecciones-desacople](../20-electronica/protecciones-desacople.md) |
| V7 | Estado de los contactos de K1 tras varios ciclos de encendido | continuidad entre nodo A y riel conmutado con la seta apretada (debe dar abierto) | [protecciones-desacople](../20-electronica/protecciones-desacople.md) |
| V8 | Saturación del sensor por encima de 15,5 A | cargar la tracción y ver dónde se aplana la lectura | [sensado-corriente](../20-electronica/sensado-corriente.md) |
| V9 | Tensión real en VOC y utilidad del pin OC | medir VOC con el multímetro y comparar con el cálculo (3,0 V esperados) | [sensado-corriente](../20-electronica/sensado-corriente.md) |
| V10 | Temperatura del AMS1117 del devkit con el LM2596 en 7,2 V | medirla con todo el 3,3 V conectado y Wi-Fi activo | [arquitectura-electrica](../20-electronica/arquitectura-electrica.md) |
| V11 | Signo de la lectura de corriente (IN- a IN+) | carga conocida y ver si Vout sube o baja desde 1,65 V | [sensado-corriente](../20-electronica/sensado-corriente.md) |
| V12 | Lectura de V_bat con la seta apretada (el divisor está post-relé) | apretar la seta y leer el ADC | [arquitectura-electrica](../20-electronica/arquitectura-electrica.md) |

## Resueltos

| # | Qué era | Resultado |
|---|---|---|
| V2 | Disipación de Q1 (IRF9540N, 117 mΩ) sin disipador | **No aplica (27-sep-2026).** Q1 quedó puenteado y no se usa. La polaridad inversa se protege con un conector que solo entra en un sentido. Ver [protecciones-desacople](../20-electronica/protecciones-desacople.md) |

Fuentes de error posibles en este análisis, que conviene tener presentes al revisar cada punto:

- U1, U4 y U5 usan el símbolo `RF_Switch:MASWSS0136` renombrado a NLAS4157. La numeración de pines
  del símbolo coincide con la del NLAS4157 en SC-88A, pero **hay que verificar que la huella
  `SOT-363_SC-70-6` esté con la misma numeración**. Si no lo estuviera, todo el razonamiento sobre
  B0/B1 cambia.
- La asignación de pines de K1 (`Relay:RAYEX-L90S`) se dedujo resolviendo el espejado del símbolo en
  el esquemático. Conviene confirmar con el multímetro cuál par es la bobina y cuál el contacto NO.
- Los valores nominales de corriente de los conectores son de catálogo genérico; el fabricante real
  que se haya comprado puede diferir.

La advertencia de numeración de pines del símbolo del ESP32 —otro caso del mismo problema— está en
[40-firmware/mapa-gpio.md](../40-firmware/mapa-gpio.md).

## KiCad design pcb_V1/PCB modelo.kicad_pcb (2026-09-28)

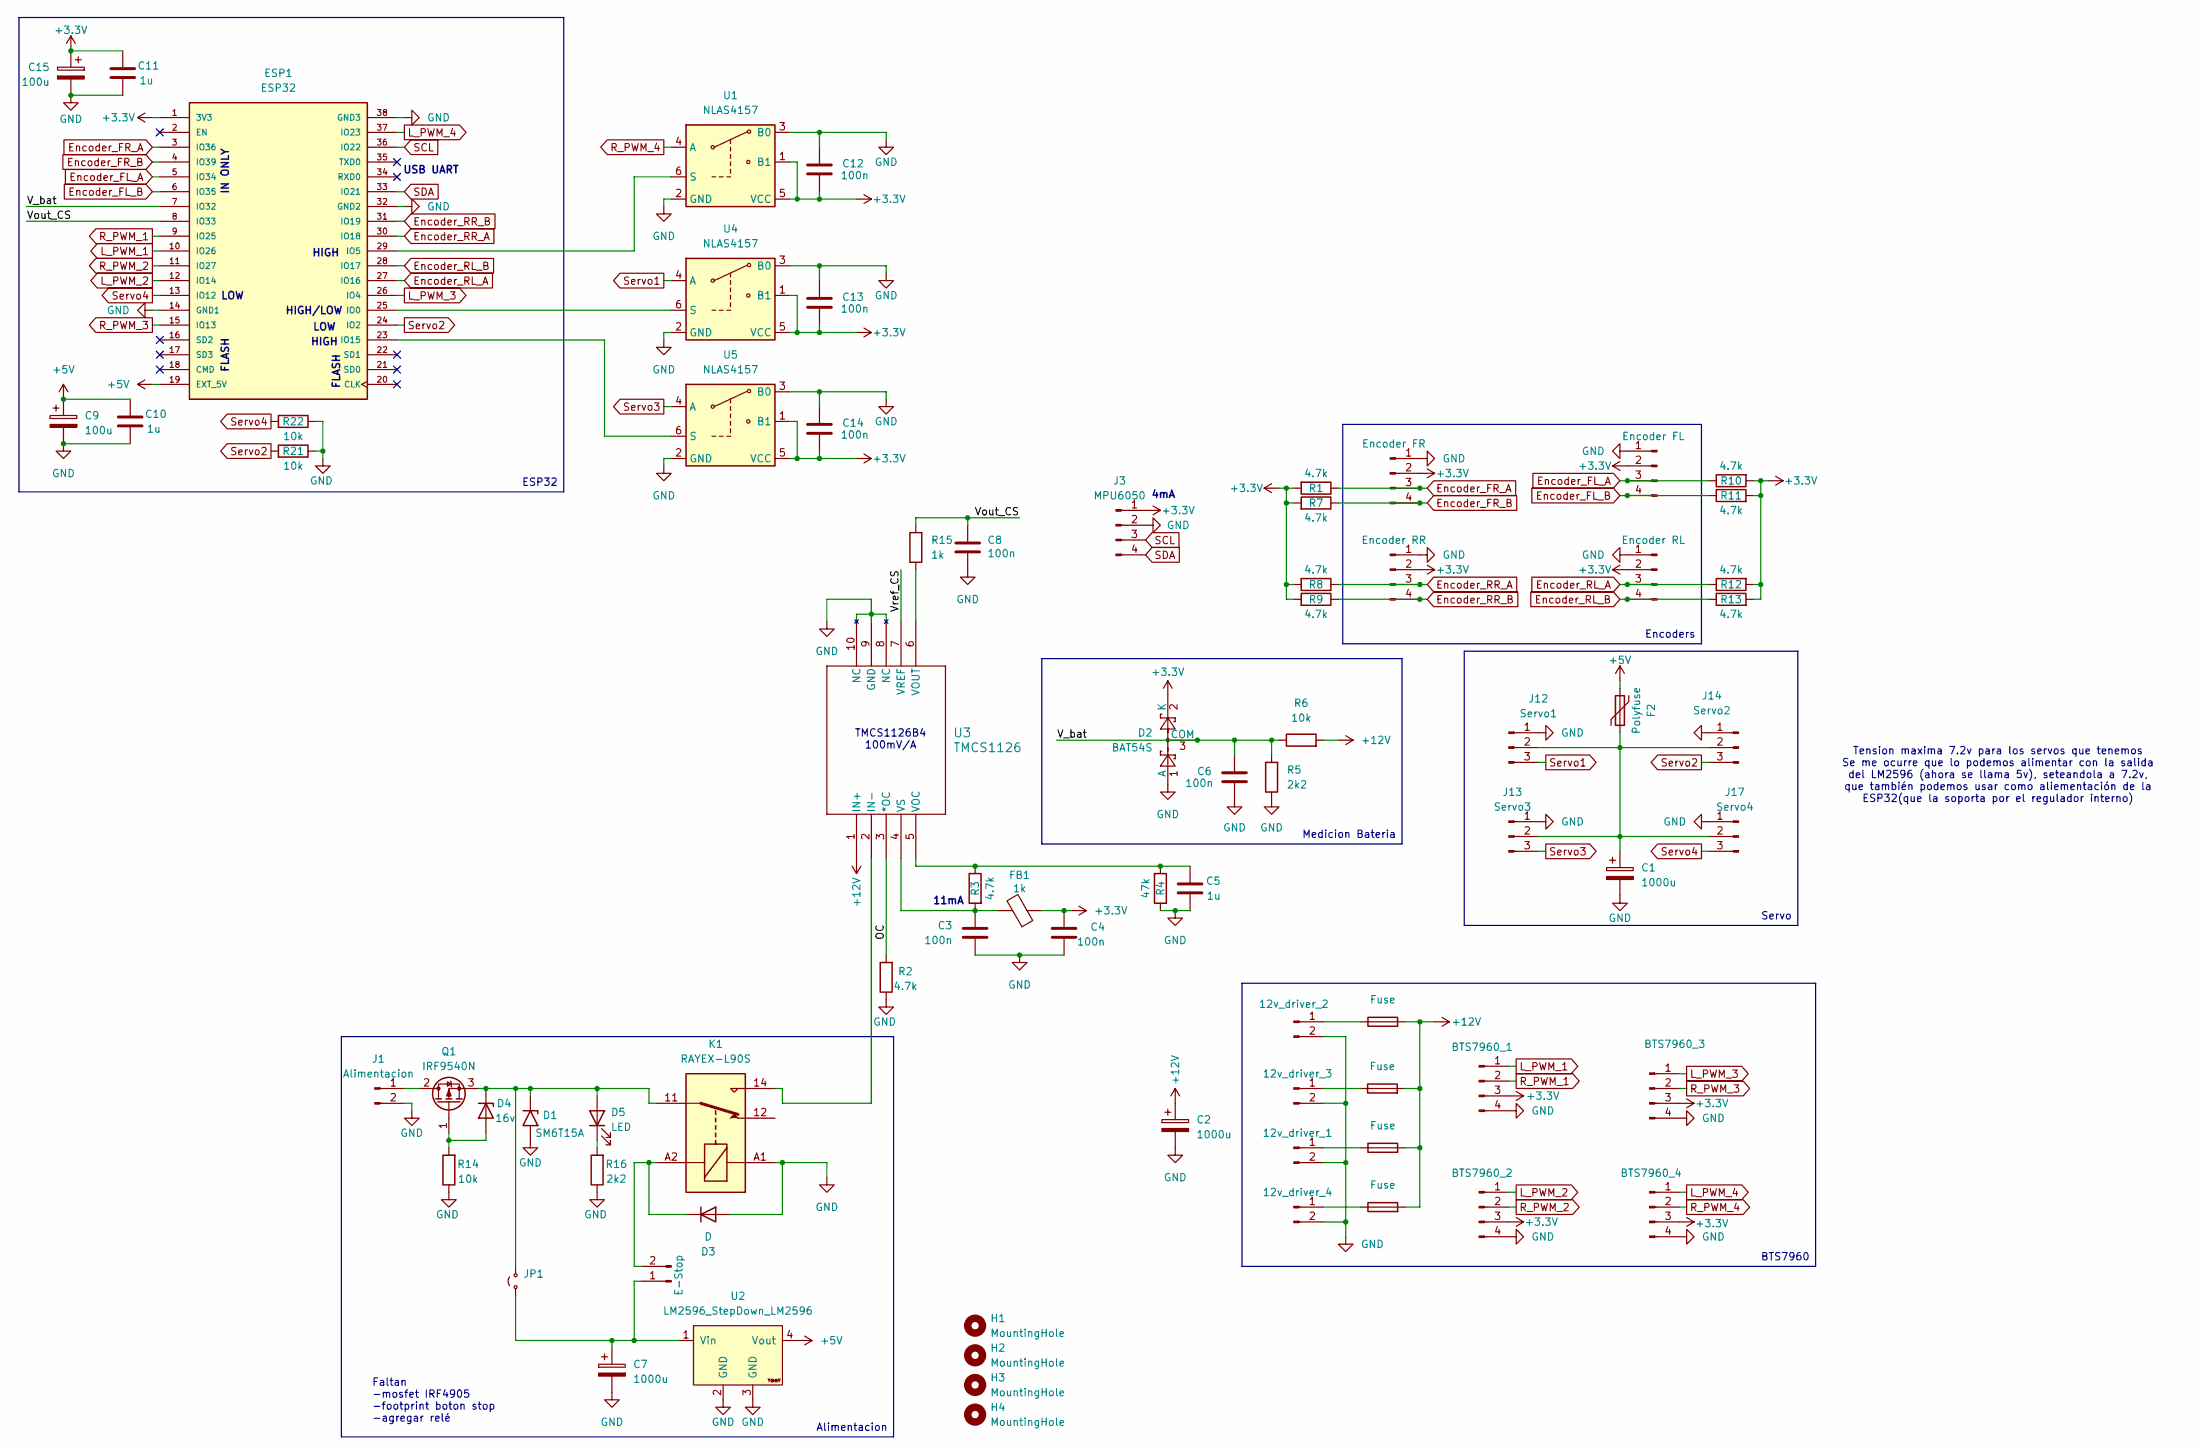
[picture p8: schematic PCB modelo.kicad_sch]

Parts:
C1, C2, C7: 1000u; CP_Radial_D10.0mm_P5.00mm
C3, C4: 100n; C_0805_2012Metric
C5, C10, C11: 1u; C_0805_2012Metric
C6, C8: 100n; C_0805_2012Metric_Pad1.18x1.45mm_HandSolder
C9, C15: 100u; C_Radial_D6.3mm_H5.0mm_P2.50mm
C12, C13, C14: 100n; C_0603_1608Metric_Pad1.08x0.95mm_HandSolder
D1: SM6T15A; D_SMB_Handsoldering
D2: BAT54S; SOT-23
D3: D; D_SMA_Handsoldering
D4: 16v; D_MiniMELF
D5: LED; LED_D3.0mm
ESP1: ESP32; esp32_39pin; PARTREV N/A
F2: Polyfuse; RV_Disc_D9mm_W3.3mm_P5mm
F3, F4, F5, F6: Fuse; FuseClip_5x20_ZH266
FB1: 1k; L_0805_2012Metric
H1, H2, H3, H4: MountingHole; MountingHole_3.2mm_M3
J1: Alimentacion; PhoenixContact_MSTBA_2,5_2-G_1x02_P5.00mm_Horizontal
J2: E-Stop; Molex_KK-254_AE-6410-02A_1x02_P2.54mm_Vertical
J3: MPU6050; Molex_KK-254_AE-6410-04A_1x04_P2.54mm_Vertical
J4: 12v_driver_2; Molex_KK-254_AE-6410-02A_1x02_P2.54mm_Vertical
J5: 12v_driver_3; Molex_KK-254_AE-6410-02A_1x02_P2.54mm_Vertical
J6: 12v_driver_1; Molex_KK-254_AE-6410-02A_1x02_P2.54mm_Vertical
J7: 12v_driver_4; Molex_KK-254_AE-6410-02A_1x02_P2.54mm_Vertical
J8: Encoder RR; Molex_KK-254_AE-6410-04A_1x04_P2.54mm_Vertical
J9: Encoder FR; Molex_KK-254_AE-6410-04A_1x04_P2.54mm_Vertical
J10: BTS7960_1; Molex_KK-254_AE-6410-04A_1x04_P2.54mm_Vertical
J11: BTS7960_2; Molex_KK-254_AE-6410-04A_1x04_P2.54mm_Vertical
J12: Servo1; Molex_KK-254_AE-6410-03A_1x03_P2.54mm_Vertical
J13: Servo3; Molex_KK-254_AE-6410-03A_1x03_P2.54mm_Vertical
J14: Servo2; Molex_KK-254_AE-6410-03A_1x03_P2.54mm_Vertical
J15: BTS7960_3; Molex_KK-254_AE-6410-04A_1x04_P2.54mm_Vertical
J16: Encoder FL; Molex_KK-254_AE-6410-04A_1x04_P2.54mm_Vertical
J17: Servo4; Molex_KK-254_AE-6410-03A_1x03_P2.54mm_Vertical
J18: Encoder RL; Molex_KK-254_AE-6410-04A_1x04_P2.54mm_Vertical
J19: BTS7960_4; Molex_KK-254_AE-6410-04A_1x04_P2.54mm_Vertical
JP1: Jumper_2_Small_Open; TestPoint_2Pads_Pitch2.54mm_Drill0.8mm
K1: RAYEX-L90S; Relay_SPDT_RAYEX-L90S
Q1: IRF9540N; TO-220-3_Vertical
R1, R2, R3, R7, R8, R9, R10, R11, R12, R13: 4.7k; R_0805_2012Metric
R4: 47k; R_0805_2012Metric
R5: 2k2; R_0805_2012Metric_Pad1.20x1.40mm_HandSolder
R6: 10k; R_0805_2012Metric_Pad1.20x1.40mm_HandSolder
R14, R21, R22: 10k; R_0805_2012Metric
R15: 1k; R_0805_2012Metric_Pad1.20x1.40mm_HandSolder
R16: 2k2; R_0805_2012Metric
U1, U4, U5: NLAS4157; SOT-363_SC-70-6_tomi
U2: LM2596_StepDown_LM2596; LM2596_buck
U3: TMCS1126; SOIC10_DVG_TEX

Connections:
+3.3V: C4.1, C11.1, C12.1, C13.1, C14.1, C15.1, D2.2 (K), ESP1.1 (3V3), FB1.1, J3.1, J8.2, J9.2, J10.3, J11.3, J15.3, J16.2, J18.2, J19.3, R1.2, R7.2, R8.2, R9.2, R10.2, R11.2, R12.2, R13.2, U1.1 (B1), U1.5 (VCC), U4.1 (B1), U4.5 (VCC), U5.1 (B1), U5.5 (VCC)
+5V: C9.1, C10.1, ESP1.19 (EXT_5V), F2.2, U2.4 (Vout)
+12V: C2.1, F3.2, F4.2, F5.2, F6.2, R6.2, U3.1 (IN+)
/OC: R2.2, U3.3 (*OC)
/V_bat: C6.2, D2.3 (COM), ESP1.7 (IO32), R5.2, R6.1
/Vout_CS: C8.2, ESP1.8 (IO33), R15.2
/Vref_CS: U3.7 (VREF)
Encoder_FL_A: ESP1.5 (IO34), J16.3, R10.1
Encoder_FL_B: ESP1.6 (IO35), J16.4, R11.1
Encoder_FR_A: ESP1.3 (IO36), J9.3, R1.1
Encoder_FR_B: ESP1.4 (IO39), J9.4, R7.1
Encoder_RL_A: ESP1.27 (IO16), J18.3, R12.1
Encoder_RL_B: ESP1.28 (IO17), J18.4, R13.1
Encoder_RR_A: ESP1.30 (IO18), J8.3, R8.1
Encoder_RR_B: ESP1.31 (IO19), J8.4, R9.1
GND: C1.2, C2.2, C3.2, C4.2, C5.2, C6.1, C7.2, C8.1, C9.2, C10.2, C11.2, C12.2, C13.2, C14.2, C15.2, D1.2 (A2), D2.1 (A), D3.2 (A), ESP1.14 (GND1), ESP1.32 (GND2), ESP1.38 (GND3), J1.2, J3.2, J4.2, J5.2, J6.2, J7.2, J8.1, J9.1, J10.4, J11.4, J12.1, J13.1, J14.1, J15.4, J16.1, J17.1, J18.1, J19.4, K1.A1, R2.1, R4.1, R5.1, R14.1, R16.1, R21.1, R22.1, U1.2 (GND), U1.3 (B0), U2.2 (GND), U2.3 (GND), U3.8 (NC), U3.9 (GND), U3.10 (NC), U4.2 (GND), U4.3 (B0), U5.2 (GND), U5.3 (B0)
L_PWM_1: ESP1.10 (IO26), J10.1
L_PWM_2: ESP1.12 (IO14), J11.1
L_PWM_3: ESP1.26 (IO4), J15.1
L_PWM_4: ESP1.37 (IO23), J19.1
unnamed: D1.1 (A1), D4.1 (K), D5.2 (A), JP1.2 (B), K1.11, Q1.3 (S)
unnamed: D3.1 (K), J2.2, K1.A2
unnamed: D4.2 (A), Q1.1 (G), R14.2
unnamed: D5.1 (K), R16.2
unnamed: ESP1.25 (IO0), U4.6 (S)
unnamed: ESP1.29 (IO5), U1.6 (S)
unnamed: ESP1.23 (IO15), U5.6 (S)
unnamed: J1.1, Q1.2 (D)
unnamed: C7.1, J2.1, JP1.1 (A), U2.1 (Vin)
unnamed: F3.1, J4.1
unnamed: F4.1, J5.1
unnamed: F5.1, J6.1
unnamed: F6.1, J7.1
unnamed: C1.1, F2.1, J12.2, J13.2, J14.2, J17.2
unnamed: K1.14, U3.2 (IN-)
unnamed: C5.1, R3.1, R4.2, U3.5 (VOC)
unnamed: R15.1, U3.6 (VOUT)
unnamed: C3.1, FB1.2, R3.2, U3.4 (VS)
R_PWM_1: ESP1.9 (IO25), J10.2
R_PWM_2: ESP1.11 (IO27), J11.2
R_PWM_3: ESP1.15 (IO13), J15.2
R_PWM_4: J19.2, U1.4 (A)
SCL: ESP1.36 (IO22), J3.3
SDA: ESP1.33 (IO21), J3.4
Servo1: J12.3, U4.4 (A)
Servo2: ESP1.24 (IO2), J14.3, R21.2
Servo3: J13.3, U5.4 (A)
Servo4: ESP1.13 (IO12), J17.3, R22.2

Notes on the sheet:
IN ONLY
Faltan -mosfet IRF4905 -footprint boton stop -agregar relé
HIGH
Tension maxima 7.2v para los servos que tenemos Se me ocurre que lo podemos alimentar con la salida del LM2596 (ahora se llama 5v), seteandola a 7.2v, que también podemos usar como aliementación de la ESP32(que la soporta por el regulador interno)
TMCS1126B4 100mV/A
HIGH/LOW
4mA
FLASH
USB UART
11mA
LOW
BTS7960
Alimentacion
Medicion Bateria
Encoders
ESP32
Servo

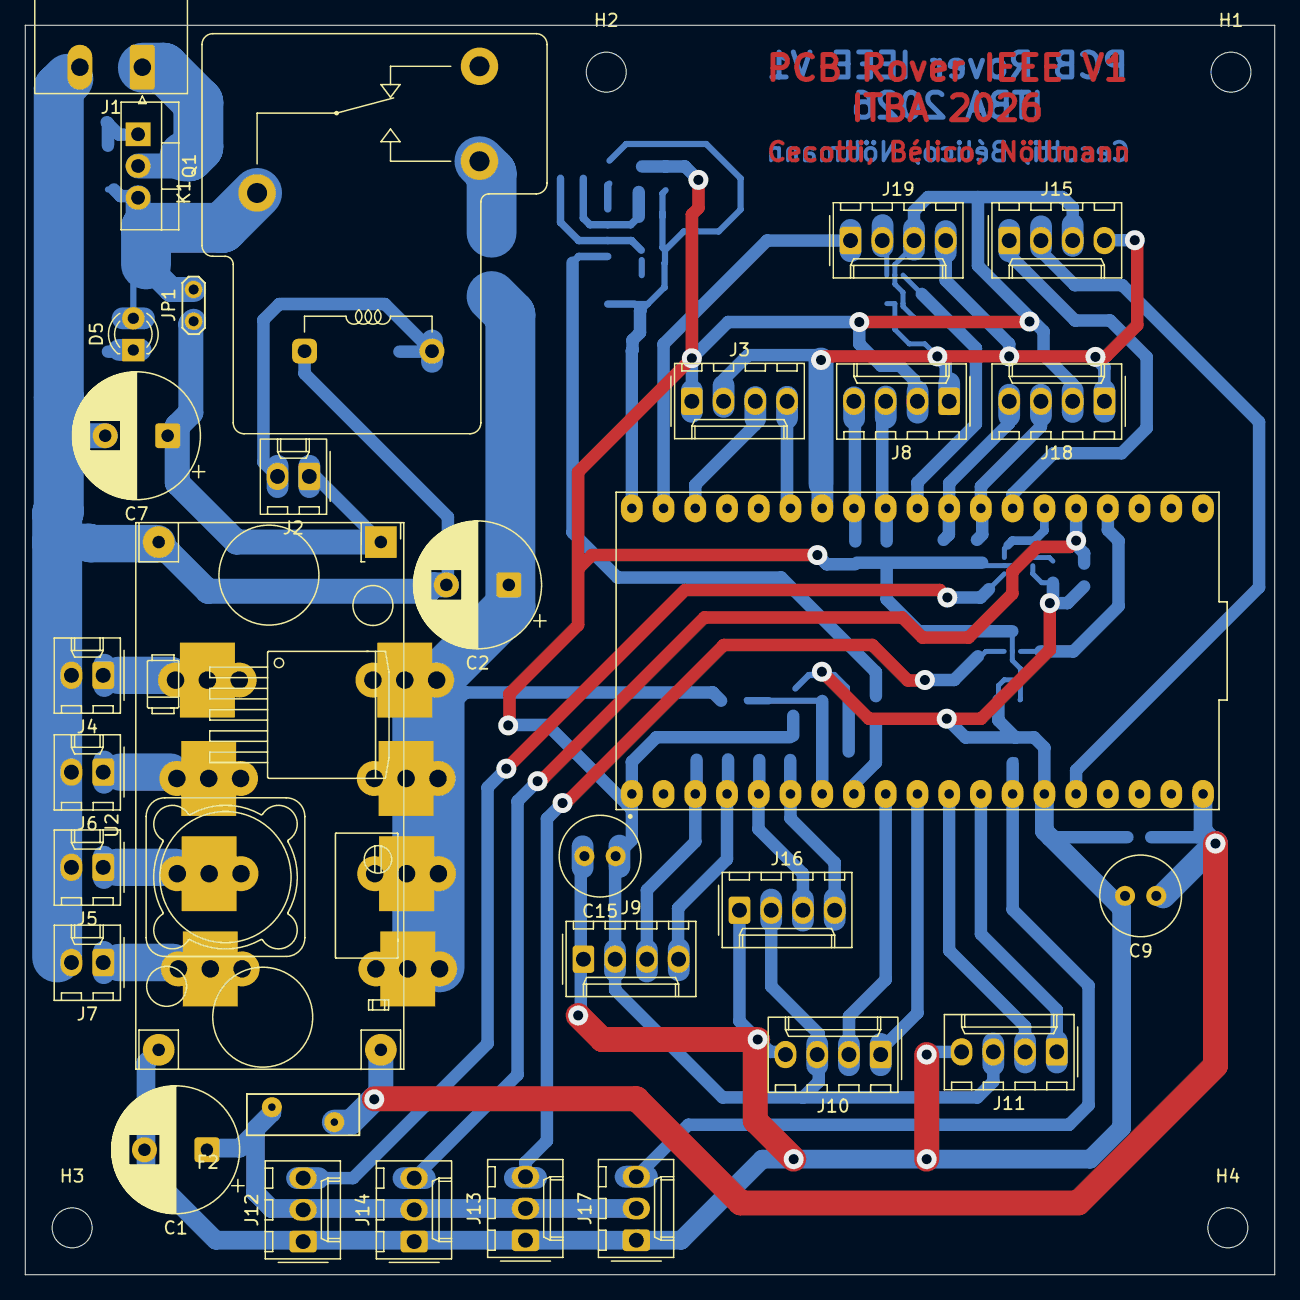
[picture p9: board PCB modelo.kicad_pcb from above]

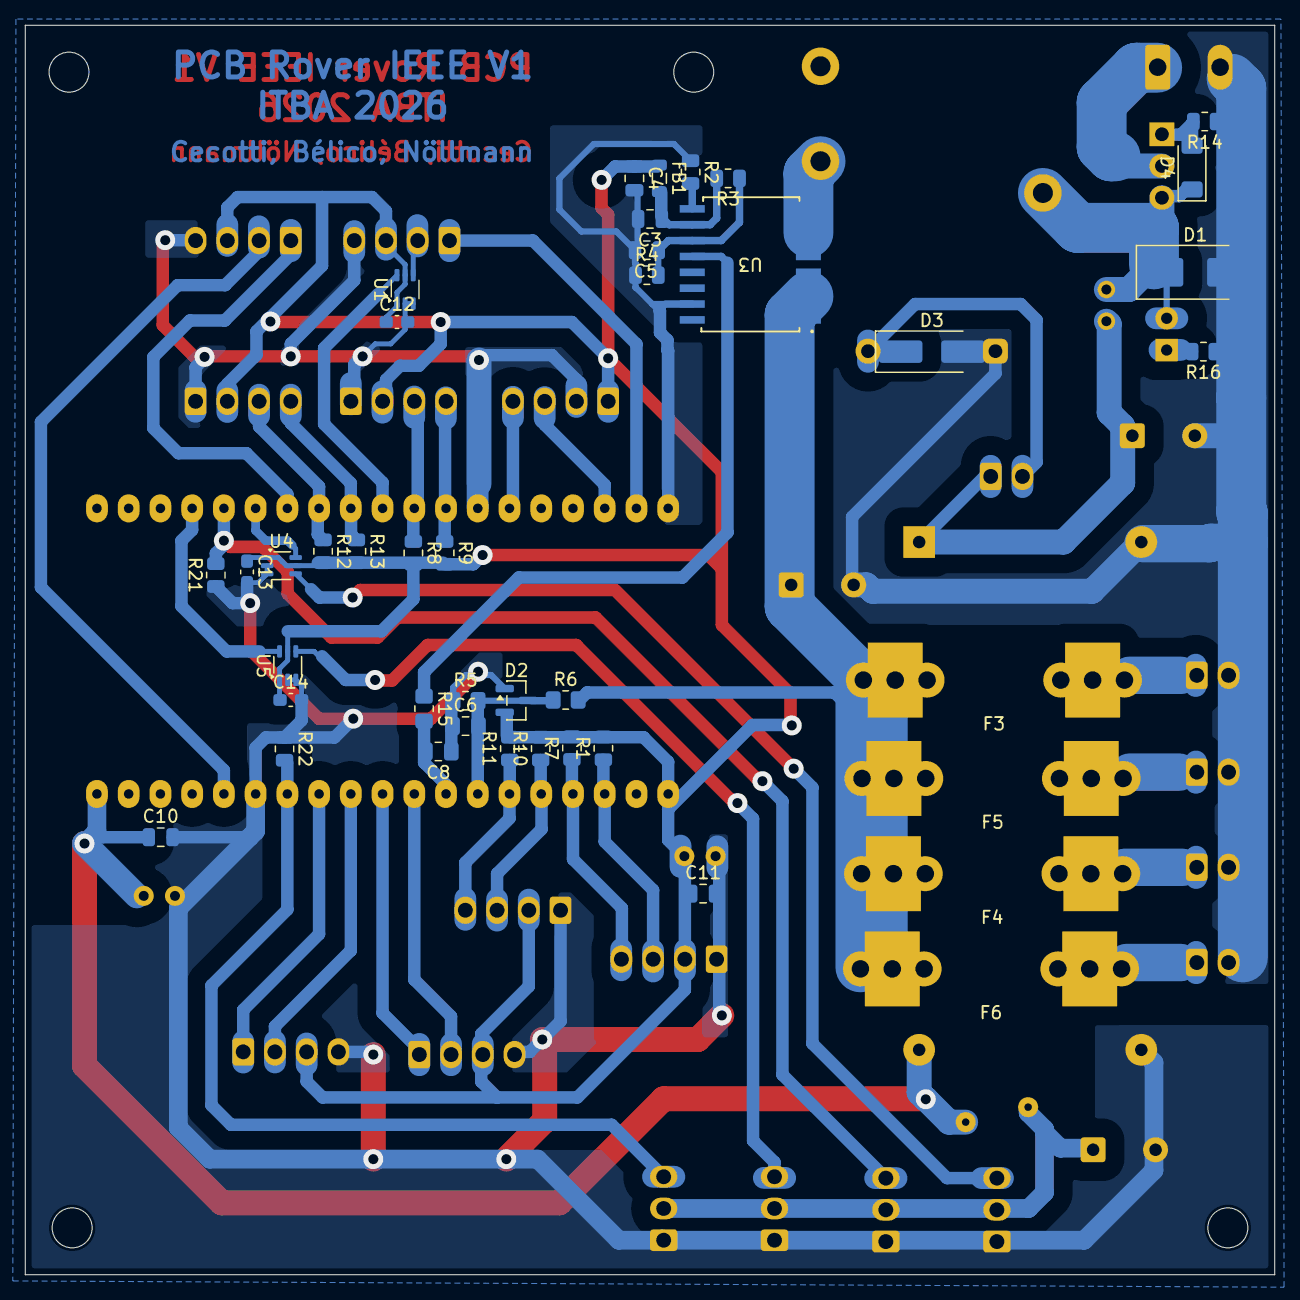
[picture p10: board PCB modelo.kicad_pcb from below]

Board: 2 copper layers, 100.0 x 100.0 mm, 76 parts (41 on the bottom side), 47 nets.

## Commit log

2026-09-27 Estado inicial del subsistema de Electrónica y Potencia
    Documentación del rover ERC: contexto maestro, requisitos del rover
    final, modelo a escala (electrónica, PCB, firmware, ensayos),
    componentes, proveedores, archivo histórico y material de la
    presentación de ingreso.
2026-09-27 Plan de ensayos rev. 2.0 del modelo y cadena de medición con ADS1115 + ACS712
    - Reescribe el plan de ensayos: Ensayo 0 (ángulo de deslizamiento), calibración,
    A, A' (cadena bajo modulación), B, C, D0 (ensayo de método) y D definitivo.
    - Instrumentación: ADS1115 comprado; ACS712 a bordo en la pata de motor de una
    rueda delantera; corrección por ciclo de trabajo del TMCS (mide D·I_motor);
    el TMCS no puede estar en el Ensayo A; en arena barra y corriente difieren
    por la resistencia de compactación.
    - Escala: las ruedas del modelo miden 150 mm, incompatibles con ~5,5 kg.
    Decisión pendiente entre reimprimir (recomendado) o lastrar.
    - PCB: pull-up en L_PWM_4 (V1 mitigado, sin v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
2026-09-28 Guía de ingreso en docx y proyecto de KiCad para descarga
    - Guía de ingreso (audiovisual-presentacion/guia-ingreso-EyP-2026-09.docx): resumen del repo para
    los ingresantes, con links a GitHub en cada sección. Corte al 28-sep-2026.
    - pcb_V1/: proyecto de KiCad de la placa del modelo, para que el equipo lo pueda descargar. El
    análisis ya está asentado en los markdown de 20-modelo-escala/.
    - CLAUDE.md, README.md y 00-estado-actual.md: la regla "los archivos de KiCad no viven acá" pasa a
    "están en pcb_V1/ para descargar". README suma pcb_V1/ y audiovisual-presentacion/ al árbol y al
    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
    [PCB modelo.kicad_pcb, PCB modelo.kicad_sch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]
2026-09-28 Correcciones a guía y presentación de ingreso, y script subir-cambios.bat
    - Guía de ingreso (.docx) y presentación (.pptx) con las correcciones de Matías.
    - subir-cambios.bat: doble clic sube todo lo cambiado en la carpeta principal
    a main (commit, rama temporal, PR, merge y borrado de la rama). No cambia
    de rama; si la carpeta no está en main se detiene.
    - .gitattributes: los .bat siempre con CRLF.
2026-10-29 cambio lectura I2C
